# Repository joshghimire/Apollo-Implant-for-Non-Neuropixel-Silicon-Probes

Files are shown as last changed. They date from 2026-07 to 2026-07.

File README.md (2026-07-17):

# Apollo-Implant-for-Non-Neuropixel-Silicon-Probes
 

A modification of the Apollo chronic implant system which allows Neuronexus probes with 64ch Omnetics Connectors and Cambridge Neurotech probes with the integrated 128 channel ASSY-350 headstage to be chronically implanted with dental cement, yet recovered after the experiment for cleaning and reuse.



The original e-life paper can be found [here](<https://elifesciences.org/articles/98522>), and the github with the files is [here](https://github.com/Coen-Lab/chronic-neuropixels)

The original apollo implant was designed for neuropixels, and consists  of 2 parts:

1)The payload module<br>
2)The docking module

Neuropixel probes get glued/cemented onto the payload module, which slides and screws into the docking module. During the surgery, you implant this docking + payload module assembly, and apply cement ONLY to the docking module. After your experiment, you anesthetize, unscrew the payload module from the docking module and slowly explant the probe from the brain.

This gives the stability of a probe that is cemented onto the skull, while allowing for recovery and reuse.

Unfortunately, the Apollo implant was designed only for neuropixel probes, which have a detatchable ribbon cable. This is NOT the case for Neuronexus and Cambridge Neurotech silicon probes, and posed an immense challenge.

Therefore, my modifications have 3 parts:<br>
1)A payload module<br>
 

2)A docking module with front panel<br>
 

3)A back panel<br>
 Screenshot 2026-07-15 at 4 23 19 PM

The general steps for assembly are as follows:

1) Heat solder m1 brass inserts into both holes of the payload module<br>
2) Superglue the probe (the probe interface; the part where the shanks are coming from) to the payload module<br>
3) Carefully insert the payload module with the probe into the docking module w/ front panel (I do this by hand, its actually not bad if you do it slowly on a flat table).<br>
4) Gently slide the ribbon cable + board into the front panel<br>
By board I mean:<br>
the green board containing the Omnetics connector for Neuronexus probes<br>
or the ASSY-350 128ch integrated headstage for Cambridge Neuro probes

 
4) Combine the back panel with the front panel  

My modifications were done on top another modification of the original Apollo implant ([the NP2_SingleProbeDockingWithHeadstage_ANGLED](https://github.com/Coen-Lab/chronic-neuropixels/tree/main/XtraModifications/Mouse_FreelyMoving) redesign by Shahaf Weiss (Max-Planck institute for brain-research, Frankfurt am Main, Germany Email: shahaf.weiss@brain.mpg.de)

Note: there is a newer attempt at a screwless solution (screwing/unscrewing exerts off-axis forces to probes, posing a risk to fragile probes like the 15um thick Buzsaki multi-shank probes), called ScrewX [github link](https://github.com/NP-HarrisLab/Harris-Lab-Neuropixels-Fixture-Design), [BioRxiv link](https://www.biorxiv.org/content/10.64898/2026.01.06.697790v1), but I haven't played around with re-designing that yet.

The original files were made in Autodesk Inventor.<br>
As of 7/2026, the CA2 implant pieces are Inventor .ipt files (TODO import to Fusion),br.
The mPFC implant pieces are Fusion.f3z (with .3mf and .stl files for direct printing) 

Note: The Cambridge Neurotech probes with the integrated ASSY-350 headstages do not let you access each electrode site to recoat with PEDOT. So each probe has a limited amount of uses. Nuber of implants of these probes can be maximized if the probe is immediately dipped in ddH20 after explantation, followed by submerging in trypsin EDTA and scrubbing the electrode sites against a hard boiled egg with a micromanipulatior as described in this [paper](https://pubmed.ncbi.nlm.nih.gov/38865216/)

CN_3521-2_ProbeImpedances_SplitYAxis

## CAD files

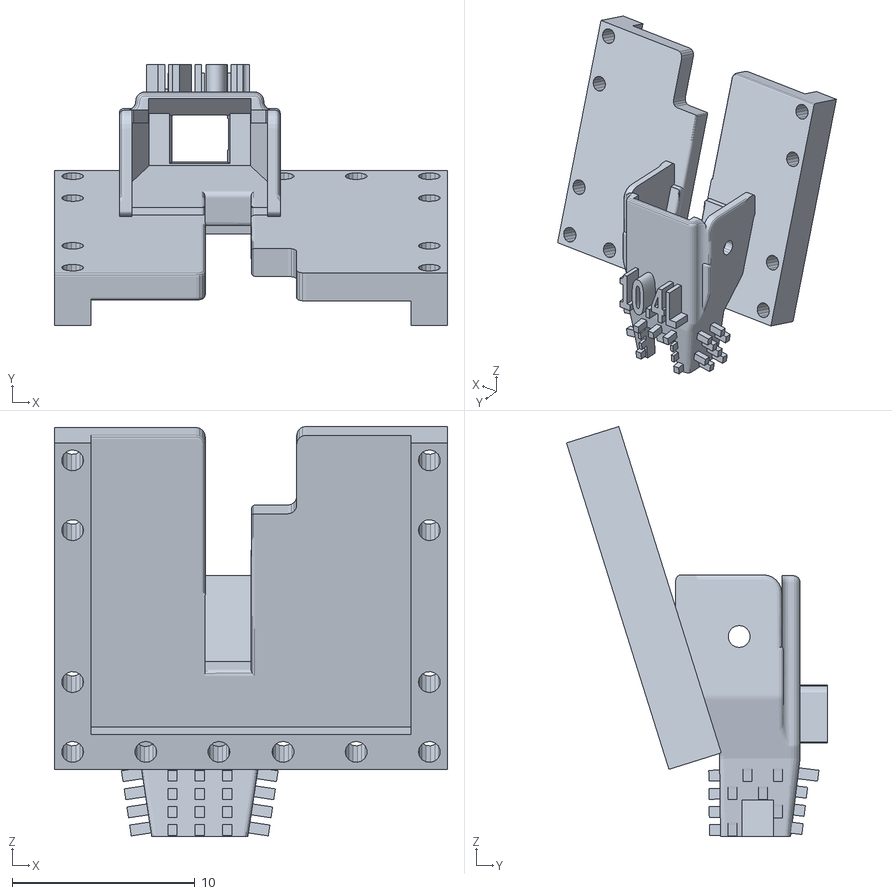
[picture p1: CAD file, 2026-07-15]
CambridgeNeuro_ASSY350_Left_CA2/Checkpoint10.4_LeftCA2_NP2_SingleProbeDockingWithHeadstageCentered_Angled_Apollo_ASSY350_Mod.stl
21.5 x 14.3 x 22.4

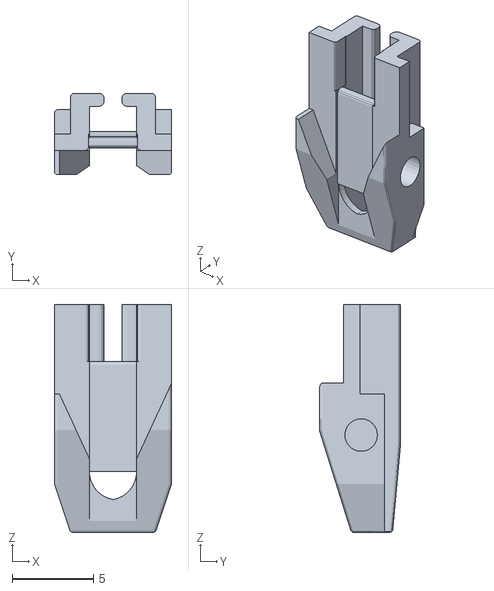
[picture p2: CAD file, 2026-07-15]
CambridgeNeuro_ASSY350_Left_CA2/Checkpoint10.1_NP2_SingleProbeMiniaturePayload.stl
7.20 x 5.00 x 14.0

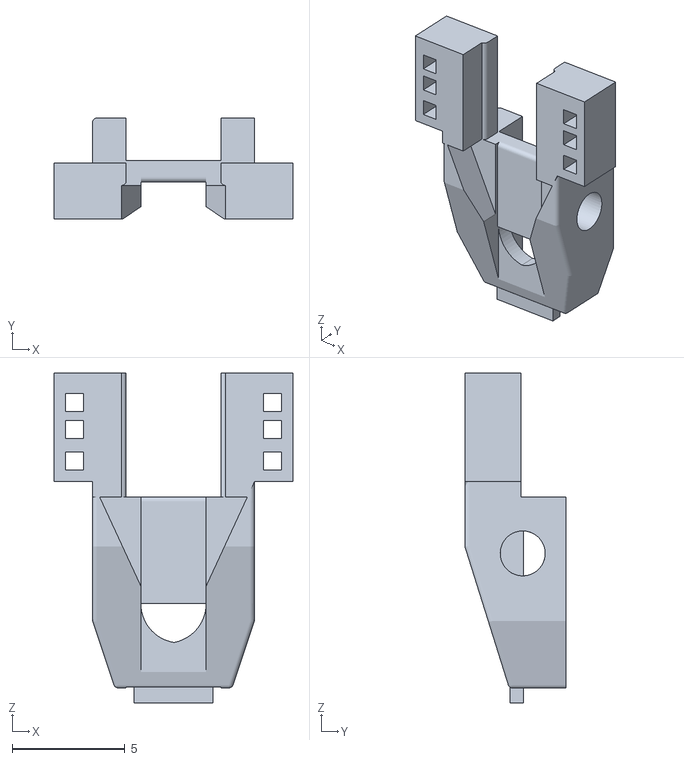
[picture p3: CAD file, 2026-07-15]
Neuronexus_Omnetics_Left_mPFC/Checkpoint10.4NP2_SingleProbeMiniaturePayload_ForNNXMPFCv3.stl
10.6 x 4.50 x 14.7

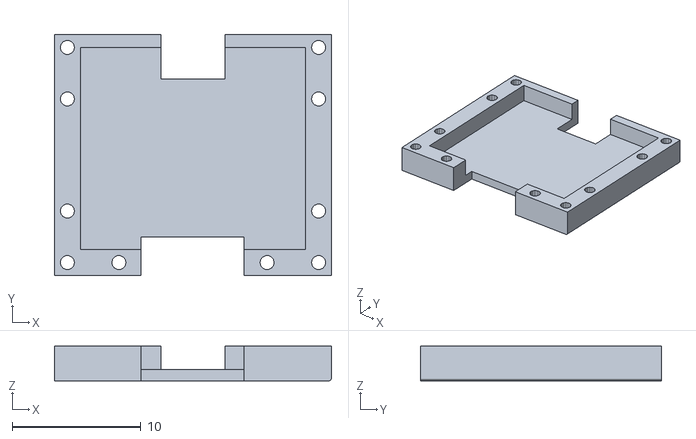
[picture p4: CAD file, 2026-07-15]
CambridgeNeuro_ASSY350_Left_CA2/Checkpoint10.2_BackCover.stl
21.5 x 18.7 x 2.70

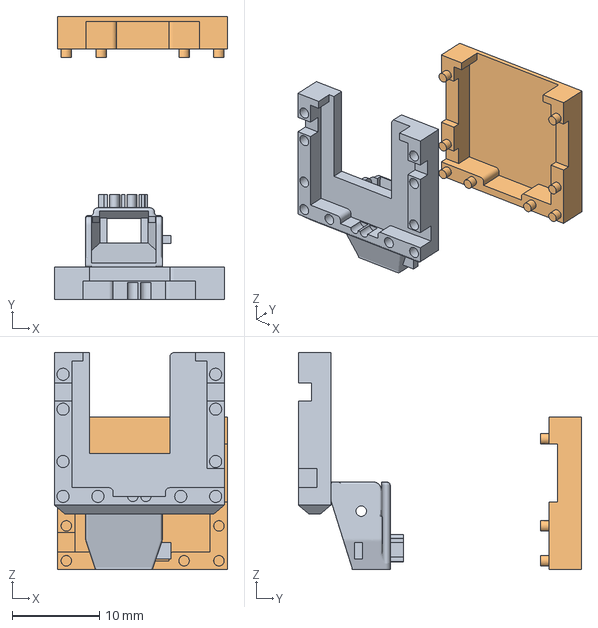
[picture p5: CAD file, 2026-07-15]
Neuronexus_Omnetics_Left_mPFC/Checkpoint10.11_BackCoverNNX.3mf
19.9 x 32.5 x 24.9 mm
Checkpoint10.11_mPFC_SingleProbeDockingWithNNXHeadstage
Checkpoint10.11_BackCoverNNX.stl

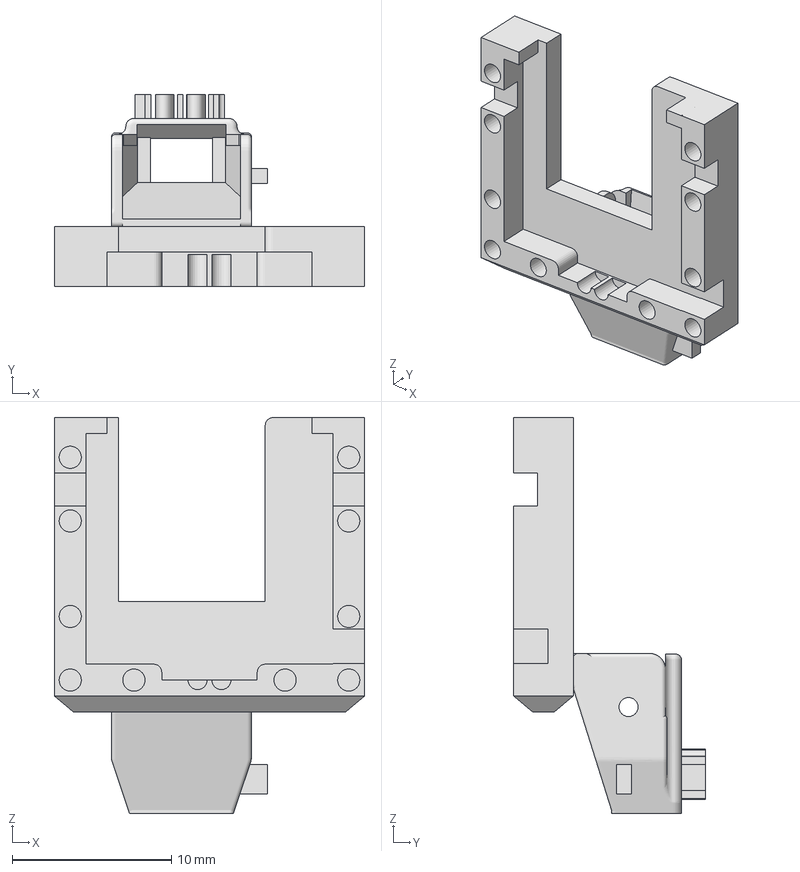
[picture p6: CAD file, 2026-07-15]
Neuronexus_Omnetics_Left_mPFC/Checkpoint10.11_mPFC_SingleProbeDockingWithNNXHeadstage.3mf
19.5 x 12.1 x 24.9 mm

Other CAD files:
CambridgeNeuro_ASSY350_Left_CA2/Checkpoint10.1_NP2_SingleProbeMiniaturePayload.ipt
CambridgeNeuro_ASSY350_Left_CA2/Checkpoint10.2_BackCover.ipt
Neuronexus_Omnetics_Left_mPFC/Checkpoint10.11_BackCoverNNX.stl
Neuronexus_Omnetics_Left_mPFC/Checkpoint10.11_mPFC_SingleProbeDockingWithNNXHeadStage.stl
Neuronexus_Omnetics_Left_mPFC/Checkpoint10.11_mPFC_SingleProbeDockingWithNNXHeadstage.f3z

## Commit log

2026-07-15 Expand README with Apollo implant modification details
    Added details about the Apollo implant modifications for Neuronexus and Cambridge Neurotech probes, including a comparison with the original design and links to related resources.
2026-07-15 Enhance README with assembly instructions and modifications
    Updated the README to include detailed assembly instructions and modifications for the Apollo implant. Clarified the distinction between the payload and docking modules, and added links for reference.
2026-07-15 Revise README for clarity and formatting improvements
    Updated README to enhance clarity and formatting, including image size adjustments and improved assembly instructions.
2026-07-15 Enhance README with images and detailed assembly steps
    Added images and updated assembly instructions for the Apollo implant system.
2026-07-15 Add files via upload
    Files For 1) Payload module that the Neuronexus probe is glued to
    2) Docking module that will hold the NNX board
    3) BackCoverNNX
    4) NNX_ProbeHolderv4. An arm/stick that holds the 1.+2.+3. assembly on the manipulator for slow probe insertion. When ready to explant, re-add pins to the holes of the 1. payload module and the 4. NN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
    [Checkpoint10.11_BackCoverNNX.3mf, Checkpoint10.11_BackCoverNNX.stl, Checkpoint10.11_mPFC_SingleProbeDockingWithNNXHeadStage.stl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]
2026-07-15 Add files via upload
    Add files via upload
    main
    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
    [Checkpoint10.11_BackCoverNNX.3mf, Checkpoint10.11_BackCoverNNX.stl, Checkpoint10.11_mPFC_SingleProbeDockingWithNNXHeadStage.stl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]
2026-07-15 Add files via upload
    Need to double-check if these are the most recent CA2 files
    [Checkpoint10.1_NP2_SingleProbeMiniaturePayload.ipt, Checkpoint10.1_NP2_SingleProbeMiniaturePayload.stl, Checkpoint10.2_BackCover.ipt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]
2026-07-15 Clarify probe compatibility in README
    Updated description to specify probe compatibility.
2026-07-17 Update README with probe usage information
    Added note about Cambridge Neurotech probes and usage.
